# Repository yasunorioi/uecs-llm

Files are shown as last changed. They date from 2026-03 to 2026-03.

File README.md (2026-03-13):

# AgriHA (uecs-llm)

LLM による温室環境制御システム — 三層自律制御アーキテクチャ

## アーキテクチャ

```
┌─────────────────────────────────────────────────────────┐
│ Raspberry Pi (AgriHA) — 全制御をオンボード実行           │
│                                                         │
│  ┌── Layer 1: 緊急制御 ──────────────────────────────┐  │
│  │ emergency_guard.sh (cron 1分)                     │  │
│  │ 高温/低温→即時開窓・ロックアウト                   │  │
│  └──────────────────────────────────────────────────┘  │
│  ┌── Layer 2: ルールベース制御 ──────────────────────┐  │
│  │ rule_engine.py (cron 5分)                         │  │
│  │ YAML定義ルール→灌水・換気・強風・降雨制御         │  │
│  │ ピタゴラスイッチ: 5段階側窓開度制御+位置追跡       │  │
│  └──────────────────────────────────────────────────┘  │
│  ┌── Layer 3: LLM予報制御 ──────────────────────────┐  │
│  │ forecast_engine.py (cron 1時間)                   │  │
│  │ NullClaw(デフォルト) or クラウドLLM API            │  │
│  │ → 天気予報+1時間制御計画生成                       │  │
│  │ plan_executor.py (cron 10分) → 計画実行            │  │
│  └──────────────────────────────────────────────────┘  │
│                                                         │
│  NullClaw Proxy (port 3001): オフラインLLM推論          │
│  unipi-daemon: センサー・リレー・MQTT・REST API         │
│  agriha-ui: ローカルWebUI (FastAPI+htmx, ポート8501)   │
│  LINE Bot: RPi上で直接稼働 (agriha-ui内)               │
├─────────────────────────────────────────────────────────┤
│ UniPi 1.1 ハードウェア                                  │
│  MCP23008 リレー(8ch) + DS18B20 + GPIO DI + Misol RS485│
│                                                         │
│ USB SIMモデム (オプション): 固定回線不要な圃場向け       │
└─────────────────────────────────────────────────────────┘
```

## 設計原則

- **下層が上層を黙らせる**: Layer 1ロックアウト中はLayer 2/3は動作しない
- **各層独立動作**: 上層が死んでも下層の安全機構は生きる
- **RPi単一構成**: 全てRaspberry Pi上で完結（VPS不要）
- **オフラインファースト**: デフォルトはNullClaw（ローカルLLM）、API不要・無料
- **マルチLLM対応**: OpenAI SDK互換でClaude/GPT/Gemini/NullClaw/Ollamaを切替可能

## NullClaw（デフォルトLLMプロバイダー）

NullClawをデフォルトLLMとして採用。APIキー不要・オフライン動作・無料。

- **nullclaw_proxy.py** (port 3001): OpenAI API互換プロキシ。NullClaw CLIをラップし `/v1/chat/completions` エンドポイントを提供
- **NullClawFallbackClient**: forecast_engine.py内のクライアント。APIキーあり→クラウドAPI優先→失敗時NullClawフォールバック。APIキーなし→NullClaw直行
- **制約**: NullClawはtool calling非対応。センサーデータはプロンプト埋め込みで代替

```
APIキーなし (デフォルト)     APIキーあり
      │                          │
      ▼                          ▼
  NullClaw直行           クラウドAPI試行
  (localhost:3001)              │
                          成功? ─┬─ Yes → クラウド応答
                                └─ No  → NullClawフォールバック
```

## LINE Bot

RPi上のagriha-ui内で直接稼働（VPS不要）。Cloudflare TunnelまたはNginx+Let's Encryptで外部公開。

- LLMプロバイダーにはNullClawFallbackClientを使用（設定画面の選択に従う）
- NullClaw使用時はtool calling不可のため、リレー制御（set_relay）は利用不可
- クラウドLLM使用時はget_sensors / get_status / set_relay のtool callingが利用可能

## ディレクトリ構成

| パッケージ | 場所 | 説明 |
|---|---|---|
| `agriha.control` | `src/agriha/control/` | 三層制御（emergency_guard, rule_engine+ピタゴラスイッチ, forecast_engine, plan_executor, window_position） |
| `agriha.control` | `src/agriha/control/nullclaw_proxy.py` | NullClaw OpenAI互換プロキシ (port 3001) |
| `agriha.daemon` | `src/agriha/daemon/` | ハードウェアデーモン（I2C, GPIO, MQTT, REST API, rain_detector, uart_co2_reader） |
| `agriha.chat` | `src/agriha/chat/` | ローカルWebUI（ダッシュボード+設定画面+サービス再起動+LINE Bot） |
| `agriha.vps` | `src/agriha/vps/` | LINE Bot VPS版（systemd + venv） |
| `firmware` | `firmware/arduino/`, `firmware/pico/` | マイコンファームウェア（Arduino W5500 PoE, Pico CircuitPython） |
| `hardware` | `hardware/kicad/` | KiCad基板設計（Grove Shield, Actuator） |
| `config` | `config/` | 設定テンプレート（rules.yaml, channel_map.yaml, forecast.yaml等） |

## セットアップ

```bash
# 1. clone
sudo git clone https://github.com/yasunorioi/uecs-llm.git /opt/agriha
cd /opt/agriha

# 2. セットアップ（ユーザー作成+venv+systemd+NullClaw全部入り）
sudo bash setup.sh

# 3. (オプション) クラウドLLMを使う場合のみAPIキー設定
sudo nano /opt/agriha/.env

# 4. 起動
sudo systemctl start unipi-daemon agriha-ui agriha-nullclaw-proxy
```

`sudo bash setup.sh` で以下が完了する:
- Python venv作成 + パッケージインストール
- NullClaw CLIインストール + agriha-nullclaw-proxy.service 有効化
- `/etc/agriha/` に設定ファイル配置
- `/var/lib/agriha/`, `/var/log/agriha/` ディレクトリ作成
- agriha システムユーザー作成 + 所有権設定
- systemd サービス有効化（unipi-daemon, agriha-ui, agriha-nullclaw-proxy）
- 三層制御 cron 設定
- Nginx + Let's Encrypt HTTPS設定（LINE Bot外部公開用）
- USB SIMモデム検出時: ModemManager + NetworkManager APN自動設定

## systemd サービス一覧

| サービス | 説明 |
|---|---|
| `unipi-daemon.service` | センサー・リレー・MQTT・REST APIデーモン |
| `agriha-ui.service` | Web UI + LINE Bot (FastAPI, ポート8501) |
| `agriha-nullclaw-proxy.service` | NullClaw OpenAI互換プロキシ (ポート3001) |
| `rain_detector.service` | 雨検知デーモン |
| `uart_co2_reader.service` | UART CO2センサー読み取りデーモン |
| `ModemManager.service` | USB SIMモデム管理（SIM使用時） |
| `certbot.timer` | Let's Encrypt証明書自動更新 |

## Web UI 設定画面

`http://<RPi-IP>:8501/settings` から以下を編集可能:

- **LLMプロバイダー**: プルダウンで NullClaw / Anthropic(Claude) / OpenAI / Gemini / Ollama 選択
- **APIキー設定**: NullClaw以外を選択した場合のみ必要
- **システムプロンプト**: Layer 3 LLMへの指示文
- **緊急閾値**: Layer 1 の高温/低温閾値
- **制御ルール**: Layer 2 の rules.yaml（YAML直接編集+構文チェック）
- **チャンネルマップ**: リレーチャンネル割当（channel_map.yaml）
- **LLM詳細設定**: forecast.yaml 直接編集（上級者向け）

## LLMプロバイダー切替

forecast_engine.py は OpenAI SDK 互換クライアント（NullClawFallbackClient）を使用。
設定画面のプルダウンから選択するか、forecast.yaml を直接編集。

| プロバイダー | base_url | APIキー | 備考 |
|---|---|---|---|
| NullClaw (デフォルト) | `http://localhost:3001/v1/` | 不要 | オフライン・無料・tool calling不可 |
| Anthropic (Claude) | `https://api.anthropic.com/v1/` | 必要 | 高精度・tool calling可 |
| OpenAI (GPT) | `https://api.openai.com/v1/` | 必要 | tool calling可 |
| Google (Gemini) | `https://generativelanguage.googleapis.com/v1beta/openai/` | 必要 | tool calling可 |
| Ollama (ローカル) | `http://localhost:11434/v1/` | 不要 | 要Ollama別途インストール |

## USB SIM / APN設定

固定回線のない圃場向けに、USB SIMモデムによるモバイル回線接続をサポート。

- setup.sh実行時にUSBモデムを自動検出し、ModemManager + NetworkManagerを設定
- APN設定はプリセットから選択: **SORACOM** (デフォルト) / IIJmio / 手動入力
- ArSprout既存USB SIM環境との互換性あり（既存設定を検出した場合は上書きしない）

## VPS LINE Bot デプロイ

VPSをLINE Bot + 農家WireGuard VPNサーバとして構築する手順。
VPSはメッセージルーターとして動作し、LLM処理は各農家のRPiで行う。

### 1. 設定ファイル編集

```bash
# VPSでリポジトリをclone
git clone https://github.com/yourname/uecs-llm.git /opt/uecs-llm
cd /opt/uecs-llm

# 環境設定を編集（ドメイン、ポート、パス等）
vi config/vps.conf
```

`config/vps.conf` の編集項目:

| 変数 | 説明 | デフォルト |
|---|---|---|
| `DOMAIN` | ドメイン名（SSL証明書・QR URL） | `toiso.fit` |
| `APP_PORT` | uvicornリッスンポート | `8443` |
| `DEPLOY_DIR` | デプロイ先シンボリックリンク | `/opt/agriha-linebot` |
| `QR_DIR` | QR画像配信ディレクトリ | `/var/www/qr` |
| `WG_INTERFACE` | WireGuardインターフェース名 | `wg-farmers` |
| `WG_PORT` | WireGuard UDPポート | `51821` |
| `WG_SERVER_IP` | WireGuardサーバIP/CIDR | `10.20.0.1/24` |

### 2. セットアップ実行

```bash
# WireGuard 農家VPNサーバ構築
sudo bash scripts/wg_farmers_vps_setup.sh

# LINE Bot + nginx + systemd セットアップ
sudo bash scripts/deploy_vps_linebot.sh --setup

# .env作成（LINE トークン、WG公開鍵等）
# NOTE: KEY=VALUE形式のみ。"export" は付けない（systemd EnvironmentFile非対応）
sudo cp /opt/agriha-linebot/.env.example /opt/agriha-linebot/.env
sudo vi /opt/agriha-linebot/.env
sudo chown www-data:www-data /opt/agriha-linebot/.env

# サービス起動
sudo systemctl start agriha-linebot
curl https://your-domain/health
```

### 3. コード更新

```bash
cd /opt/uecs-llm
sudo bash scripts/deploy_vps_linebot.sh
# → git pull + pip差分 + サービス再起動
```

### テンプレートファイル

| テンプレート | 展開先 | 説明 |
|---|---|---|
| `config/nginx-vps.conf.template` | `/etc/nginx/sites-available/${DOMAIN}` | nginx設定 |
| `systemd/agriha-linebot.service.template` | `/etc/systemd/system/agriha-linebot.service` | systemdサービス |

テンプレート内の `__DOMAIN__`, `__APP_PORT__` 等のプレースホルダは `deploy_vps_linebot.sh --setup` が `config/vps.conf` の値で自動置換する。

## テスト

```bash
pip install -e ".[dev]"
pytest tests/ -v
```

## ライセンス

MIT

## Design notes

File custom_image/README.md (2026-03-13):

# UniPi Agri HA カスタムイメージ

Arsproutからの完全移行用カスタムRaspbian イメージ

## 構成

```
Raspbian Lite 64-bit (bookworm)
├── Docker + Docker Compose
│   ├── Home Assistant（制御・ローカルUI）
│   ├── Node-RED（農業ロジック）
│   └── Mosquitto（MQTTブローカー）
├── EVOK（UniPi 1.1制御）
├── WireGuard（VPN）
├── RS485気象センサーサービス
├── 設定バックアップcron
└── カメラ対応（オプション）
```

## データ保存方針

- **ローカル（Pi）**: 制御・一時データのみ
- **クラウド（さくら）**: 長期保存（InfluxDB, Grafana, カメラ画像）
- **設定バックアップ**: 毎日クラウドへ同期

## ファイル構成

```
custom_image/
├── scripts/
│   ├── build_image.sh      # イメージビルドスクリプト
│   ├── first_boot.sh       # 初回起動時セットアップ
│   ├── install_evok.sh     # EVOK インストール
│   ├── install_docker.sh   # Docker インストール
│   └── backup_config.sh    # 設定バックアップ
├── config/
│   ├── wg0.conf.template   # WireGuard設定テンプレート
│   ├── evok.conf           # EVOK設定
│   └── settings.yaml       # デバイス固有設定
├── docker/
│   ├── docker-compose.yaml # HA + Node-RED + Mosquitto
│   └── ha-config/          # Home Assistant設定
└── overlays/
    └── config.txt          # /boot/config.txt 追記内容
```

## ビルド手順

1. Raspbian Lite 64-bit イメージをダウンロード
2. `build_image.sh` でイメージをカスタマイズ
3. SDカードに書き込み
4. 初回起動時に `first_boot.sh` が実行される

## 対応ハードウェア

- Raspberry Pi 3B/3B+/4B/Zero 2 W
- UniPi 1.1（I2C接続）
- RS485 USB-Serialアダプタ（CH341等）
- PoE IPカメラ（オプション）

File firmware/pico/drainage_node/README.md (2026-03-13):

# Drainage Sensor Node - MQTT Version

CircuitPython firmware for greenhouse drainage monitoring using DFRobot SEN0575 tipping bucket sensor with MQTT communication.

---

## Hardware Requirements

### Components
- **W5500-EVB-Pico-PoE** - Raspberry Pi Pico compatible board with Ethernet and PoE support
- **DFRobot SEN0575** - Gravity Tipping Bucket Rainfall Sensor
- **Ethernet Cable** - Cat5e or better
- **PoE Injector** - Optional, for power over Ethernet

### Wiring

#### W5500 SPI (Pre-wired on W5500-EVB-Pico-PoE)
- GP16: MISO
- GP17: CS
- GP18: SCK
- GP19: MOSI

#### DFRobot SEN0575 I2C Connection
| Sensor Pin | Pico Pin | Description |
|---|---|---|
| VCC | 3.3V | Power supply |
| GND | GND | Ground |
| SDA | GP4 | I2C Data |
| SCL | GP5 | I2C Clock |

---

## Software Requirements

### CircuitPython
- **Version**: 9.0.0 or later
- **Download**: https://circuitpython.org/board/wiznet_w5500_evb_pico/

### Required Libraries
Install these libraries to the `/lib` folder on CIRCUITPY drive:

1. **adafruit_wiznet5k** - W5500 Ethernet driver
2. **adafruit_minimqtt** - MQTT client
3. **adafruit_bus_device** - I2C device helper

Download from: https://circuitpython.org/libraries

---

## Installation

### Step 1: Flash CircuitPython
1. Download CircuitPython UF2 file for W5500-EVB-Pico
2. Hold BOOTSEL button while connecting USB
3. Drag and drop UF2 file to RPI-RP2 drive
4. Board will restart with CIRCUITPY drive

### Step 2: Install Libraries
1. Download Adafruit CircuitPython Library Bundle
2. Copy required libraries from bundle to `/lib` on CIRCUITPY:
   ```
   /lib/adafruit_wiznet5k/
   /lib/adafruit_minimqtt/
   /lib/adafruit_bus_device/
   /lib/dfrobot_rainfall.py  (included in this project)
   ```

### Step 3: Deploy Firmware
1. Copy `code.py` to root of CIRCUITPY drive
2. Copy `settings.toml` to root of CIRCUITPY drive
3. Edit `settings.toml` with your network and MQTT settings
4. Board will auto-restart and run firmware

---

## Configuration

Edit `settings.toml` before deployment:

```toml
# House identification
HOUSE_ID = "h1"

# Network (Static IP)
STATIC_IP = "192.168.1.70"
SUBNET = "255.255.255.0"
GATEWAY = "192.168.1.1"
DNS = "8.8.8.8"

# MQTT Broker
MQTT_BROKER = "192.168.1.10"
MQTT_PORT = "1883"
MQTT_USER = ""  # Optional
MQTT_PASS = ""  # Optional

# Sensor I2C Address
SENSOR_I2C_ADDR = "0x1D"

# Publish interval (seconds)
PUBLISH_INTERVAL = "600"  # 10 minutes
```

---

## MQTT Topics

### Published Topics
- `greenhouse/{HOUSE_ID}/drainage/amount` - Drainage amount (JSON)
- `greenhouse/{HOUSE_ID}/drainage/rate` - Drainage rate (JSON)
- `greenhouse/{HOUSE_ID}/drainage/count` - Tip count (JSON)
- `greenhouse/{HOUSE_ID}/drainage/status` - Online/Offline status

### Subscribed Topics
- `greenhouse/{HOUSE_ID}/drainage/reset` - Reset command (payload: "reset" or "1")

### Payload Format

**Amount:**
```json
{
  "timestamp": "2026-02-05T10:30:00",
  "amount_mm": 2.5,
  "total_mm": 15.8,
  "interval_sec": 600
}
```

**Rate:**
```json
{
  "timestamp": "2026-02-05T10:30:00",
  "rate_mm_min": 0.25
}
```

**Count:**
```json
{
  "timestamp": "2026-02-05T10:30:00",
  "count": 45
}
```

---

## Home Assistant Integration

### MQTT Discovery

Firmware automatically publishes Home Assistant MQTT Discovery configuration on startup. Sensors will appear as:

- `sensor.{house_id}_drainage_amount` - Drainage amount (mm)
- `sensor.{house_id}_drainage_rate` - Drainage rate (mm/min)

### Manual Configuration

If auto-discovery is disabled, add to `configuration.yaml`:

```yaml
mqtt:
  sensor:
    - name: "H1 Drainage Amount"
      state_topic: "greenhouse/h1/drainage/amount"
      unit_of_measurement: "mm"
      device_class: precipitation
      value_template: "{{ value_json.amount_mm }}"

    - name: "H1 Drainage Rate"
      state_topic: "greenhouse/h1/drainage/rate"
      unit_of_measurement: "mm/min"
      value_template: "{{ value_json.rate_mm_min }}"
```

---

## Operation

### Normal Operation
1. Board connects to Ethernet on startup
2. Connects to MQTT broker
3. Publishes sensor readings every 10 minutes (configurable)
4. Performs daily reset at midnight (00:00)

### Status Monitoring

**Serial Console (USB):**
```bash
# Linux/Mac
screen /dev/ttyACM0 115200

# Windows
# Use PuTTY or Tera Term
```

**Expected Output:**
```
==================================================
Drainage Sensor Node - MQTT Version
==================================================
Initializing W5500 Ethernet...
IP Address: 192.168.1.70
Initializing I2C...
Initializing DFRobot Rainfall Sensor (I2C: 0x1D)...
Sensor initialized successfully!
Setting up MQTT client (Broker: 192.168.1.10:1883)...
Connected to MQTT broker! (RC: 0)
Publishing Home Assistant MQTT Discovery...
==================================================
Starting main loop...
Publish interval: 600 seconds
==================================================
```

### LED Indicators
- **Power LED**: Solid = Board powered
- **W5500 Link LED**: Solid = Ethernet connected
- **W5500 Activity LED**: Blinking = Network traffic

---

## Troubleshooting

### Sensor Not Detected
**Symptom:** `ERROR: Sensor initialization failed!`

**Solutions:**
1. Check I2C wiring (SDA, SCL, VCC, GND)
2. Verify sensor power (3.3V)
3. Test I2C address:
   ```python
   # Add to code.py temporarily
   import board
   import busio
   i2c = busio.I2C(board.GP5, board.GP4)
   while not i2c.try_lock():
       pass
   devices = i2c.scan()
   print("I2C devices found:", [hex(d) for d in devices])
   i2c.unlock()
   ```
4. Expected address: `0x1d`

### MQTT Connection Failed
**Symptom:** `MQTT connection failed: [Errno 113] EHOSTUNREACH`

**Solutions:**
1. Verify MQTT broker IP in `settings.toml`
2. Check broker is running: `mosquitto_sub -h 192.168.1.10 -t '#' -v`
3. Check network connectivity: Ping broker from another device
4. Verify firewall allows port 1883

### No Data Published
**Symptom:** MQTT connected but no sensor data

**Solutions:**
1. Check serial console for errors
2. Verify sensor is receiving rainfall events
3. Check publish interval (default: 10 minutes)
4. Monitor MQTT topic: `mosquitto_sub -h 192.168.1.10 -t 'greenhouse/+/drainage/#' -v`

### Ethernet Not Connecting
**Symptom:** `Ethernet connection timeout`

**Solutions:**
1. Check Ethernet cable connection
2. Verify static IP settings in `settings.toml`
3. Check router/switch port is active
4. Try DHCP temporarily (modify code.py: `is_dhcp=True`)

---

## Maintenance

### Sensor Calibration
Default: 0.2794 mm per tip (factory calibration)

To recalibrate:
1. Collect known volume of water (e.g., 100ml)
2. Pour into sensor funnel
3. Count number of tips
4. Calculate: `mm_per_tip = (volume_ml / funnel_area_cm2) / tip_count * 10`
5. Update in sensor driver (requires code modification)

### Daily Reset
Sensor cumulative values reset automatically at midnight (00:00).

Manual reset:
```bash
mosquitto_pub -h 192.168.1.10 -t 'greenhouse/h1/drainage/reset' -m 'reset'
```

---

## File Structure

```
drainage_node/
├── code.py              # Main firmware
├── settings.toml        # Configuration
└── README.md            # This file

/lib/
└── dfrobot_rainfall.py  # Sensor driver
```

---

## References

- **DFRobot SEN0575 Datasheet**: https://wiki.dfrobot.com/SKU_SEN0575
- **CircuitPython Documentation**: https://docs.circuitpython.org/
- **W5500-EVB-Pico Schematic**: https://docs.wiznet.io/Product/iEthernet/W5500/w5500-evb-pico
- **MQTT Protocol**: https://mqtt.org/

---

## License

This firmware is part of the Arsprout greenhouse automation project.

**Author**: Arsprout Analysis Team
**Date**: 2026-02-05
**Version**: 1.0.0

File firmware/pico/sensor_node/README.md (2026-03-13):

# センサーノード ファームウェア

W5500-EVB-Pico2 + Grove Shield を使用したセンサーノード

## 動作確認済み (2026-02-05)

- E2E通信成功: センサー → MQTT → Mosquitto

## ハードウェア構成

| コンポーネント | 型番 | I2Cアドレス |
|---|---|---|
| メインボード | W5500-EVB-Pico2 | - |
| 温湿度センサー | SHT40 | 0x44 |
| 気圧センサー | BMP280 | 0x76 |
| CO2センサー | SCD41 | 0x62 |

## ピン配置

### I2C (Grove Shield)
- SDA: GP8
- SCL: GP9

### W5500 SPI
- SCK: GP18
- MOSI: GP19
- MISO: GP16
- CS: GP17
- RST: GP20

## 必要ライブラリ

```bash
circup install adafruit_sht4x adafruit_bmp280 adafruit_scd4x adafruit_minimqtt adafruit_requests
```

## MQTT トピック

- `greenhouse/sensors` - センサーデータ (JSON)

### ペイロード例

```json
{"temp": 25.3, "hum": 56.4, "press": 1004.3}
```

## 使い方

1. `code.py` を CIRCUITPY ドライブにコピー
2. `settings.toml` でMQTTブローカーのIPを設定
3. 電源投入で自動起動

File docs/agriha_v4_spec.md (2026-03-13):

# AgriHA v4 仕様書

> **Version**: 4.0-draft
> **Generated**: 2026-03-04
> **Source**: v3-rebuild branch + cmd_304 research + Memory MCP
> **正データ: v3-rebuildブランチの実コードのみ。v3.x設計書は参考程度。**

---

## §1 機能一覧

### 1.1 機能カタログ

| # | カテゴリ | 機能 | ステータス | 優先度 | 実装場所 |
|---|---|---|---|---|---|
| F01 | リモート制御 | LINE Bot「開けろ/閉めろ」 | RPi移植設計済み | P0 | src/agriha/chat/app.py + linebot_handler.py |
| F02 | 状況確認 | LINE Bot「今どうなってる？」 | RPi移植設計済み | P0 | src/agriha/chat/app.py + linebot_handler.py |
| F03 | 異常通知 | emergency_guard.sh LINE通知 | 実装済み | P1 | src/agriha/control/emergency_guard.sh |
| F04 | 自動制御 | Layer1: 緊急停止 | 実装済み | P1 | src/agriha/control/emergency_guard.sh |
| F05 | 自動制御 | Layer2: ルールベース+ピタゴラスイッチ | 実装済み | P2 | src/agriha/control/rule_engine.py + window_position.py |
| F06 | 自動制御 | Layer3: LLM 1時間予報 | 実装済み | P2 | src/agriha/control/forecast_engine.py |
| F07 | 自動制御 | 計画実行（plan_executor） | 実装済み | P2 | src/agriha/control/plan_executor.py |
| F08 | 自動制御 | 日射比例灌水 | 実装済み | P2 | src/agriha/control/rule_engine.py |
| F09 | UI | ダッシュボード+設定画面+サービス再起動 | 実装済み | P2 | src/agriha/chat/ (templates/static) |
| F10 | UI | Chat窓（Claude対話） | 実装済み | P2 | src/agriha/chat/app.py |
| F11 | HW抽象化 | unipi-daemon（センサー+リレー） | 実装済み | P1 | src/agriha/daemon/ |
| F12 | HW抽象化 | 雨検知（rain_detector） | 実装済み | P2 | src/agriha/daemon/rain_detector.py |
| F13 | HW抽象化 | CO2読取（uart_co2_reader） | 実装済み | P3 | src/agriha/daemon/uart_co2_reader.py |
| F14 | インフラ | カメラ定点撮影 | 実装済み | P3 | scripts/agriha-capture.sh |
| F15 | インフラ | Nginx統合 | 設計済み(config/nginx.conf) | P3 | config/nginx.conf |
| F16 | 蒸留 | 判断パターン蒸留パイプライン | 部分実装 | P4 | src/agriha/control/distiller.py |
| F17 | UI | 反省会モード（週次LINE Bot） | 設計済み(config有) | P4 | config/reflection.yaml |
| F18 | 設定 | channel_map.yaml外部設定 | 実装済み | P1 | config/channel_map.yaml + channel_config.py |
| F19 | ネットワーク | USB SIM / APN設定UI | 設計済み | P1 | src/agriha/chat/app.py (settings画面) + ModemManager |
| F20 | ネットワーク | HTTPS証明書管理 | 設計済み | P1 | certbot + Nginx |
| F21 | 自動制御 | ピタゴラスイッチ段階制御 | **実装済み** | P2 | src/agriha/control/rule_engine.py + window_position.py |

### 1.2 優先度定義

| 優先度 | 意味 | 基準 |
|---|---|---|
| P0 | 最重要 | 農家が毎日使う。停止＝業務不能 |
| P1 | 必須 | 安全装置。停止＝作物リスク |
| P2 | 重要 | 自動制御の中核。手動で代替可 |
| P3 | 便利 | あると便利。なくても運用可 |
| P4 | 将来 | 構想段階。1年分データ蓄積後に着手 |

### 1.3 設計思想（Memory MCP: tono-preferences）

- **マクガイバー精神**: シンプル・ローコスト・手元の道具で解決
- **三層構造**: 爆発（緊急停止）→ガムテ（ルールベース）→知恵（LLM）。下ほど確実、どの層が欠けても下が支える
- **怒り駆動開発**: LINEへのクレーム→system_prompt.txtに追記→制御ロジックになる
- **LLM自然減衰**: 初期はLLM毎時→パターン蓄積→ルールに蒸留→API代が自然減衰
- **機能優先順位**: 1位「開けろ/閉めろ」> 2位「今どうなってる？」> 3位 異常値通知 > 4位 自動制御

---

## §2 アーキテクチャ

### 2.1 システム構成図（2ノード + VPSオプション）

```
LINE Platform                    VPS (オプション)
  │ Webhook POST                 ┌──────────────────────────┐
  │ (HTTPS/443)                  │ Grafana + InfluxDB       │
  │                              │ + Telegraf               │
  │                              │ :3000 (監視用、必須ではない) │
  │                              └──────────────────────────┘
  │
  │  Let's Encrypt + 固定IP (USB SIM)
  │
┌─┴─────────────────────────────────────────────────────────┐
│                RPi (Raspberry Pi 4B)                        │
│                                                             │
│  ┌─────────────┐  ┌─────────────┐  ┌─────────────┐       │
│  │ unipi-daemon│  │ agriha-ui   │  │ Mosquitto   │       │
│  │ (systemd)   │  │ (systemd)   │  │ MQTT Broker │       │
│  │ :8080       │  │ :8501       │  │ :1883       │       │
│  │ REST API    │  │ FastAPI     │  │             │       │
│  │ +MQTT pub   │  │ Chat+Dash   │  │             │       │
│  │             │  │ +LINE Bot   │  │             │       │
│  │             │  │ +Settings   │  │             │       │
│  └──────┬──────┘  └──────┬──────┘  └──────┬──────┘       │
│         │                │                │               │
│         │   ┌────────────┴────────┐       │               │
│         │   │ cron scripts        │       │               │
│         │   │ emergency_guard.sh  │◄──────┘               │
│         │   │ rule_engine.py      │  MQTT                 │
│         │   │ forecast_engine.py  │  subscribe            │
│         │   │ plan_executor.py    │                        │
│         │   └─────────────────────┘                        │
│         │                                                  │
│  ┌──────┴──────┐  ┌──────────────┐  ┌──────────────┐     │
│  │ NullClaw    │  │ Nginx        │  │ USB SIM      │     │
│  │ Proxy       │  │ (HTTPS/443)  │  │ ドングル     │     │
│  │ :3001       │  │ + HTTP/80    │  │ (セルラー)   │     │
│  └─────────────┘  └──────────────┘  └──────────────┘     │
│                                                             │
│  ┌──────────────────────────────────────────────────┐     │
│  │ Hardware Layer                                     │     │
│  │ I2C: MCP23008 → 8ch Relay (ch1-8)                │     │
│  │ 1-Wire: DS18B20 → 内温                            │     │
│  │ UART RS485: Misol WH65LP → 気象(温湿度/風/雨)     │     │
│  │ UART: CDM7160/K30/SCD30 → CO2                    │     │
│  │ GPIO: DI07-14 → 緊急スイッチ                       │     │
│  └──────────────────────────────────────────────────┘     │
│                                                             │
│  ┌──────────────────┐  ┌──────────────────┐               │
│  │ rain_detector    │  │ uart_co2_reader  │               │
│  │ (systemd)        │  │ (systemd)        │               │
│  └──────────────────┘  └──────────────────┘               │
└─────────────────────────────────────────────────────────────┘
           │
    ┌──────┴──────┐
    │  ハウス内    │
    ├─────────────┤
    │ Pico W      │ Arduino, W5500 Ethernet
    │ env_node    │ → MQTT → unipi-daemon
    │ solar_node  │
    └─────────────┘
```

### 2.2 ディレクトリ構成

> **2026-03-13更新**: unipi-agri-ha / uecs-pico-gateway から全アクティブコードを統合し、uecs-llm をモノレポ化。

```
uecs-llm/
├── config/                    # 全設定ファイル統一
│   ├── channel_map.yaml       # リレーch↔機器マッピング
│   ├── crop_irrigation.yaml   # 灌水パラメータ
│   ├── emergency.conf         # 緊急閾値
│   ├── forecast.yaml          # LLMプロバイダー・パラメータ
│   ├── network.yaml           # ネットワーク設定
│   ├── nginx.conf             # Nginx設定テンプレート
│   ├── reflection.yaml        # 反省会モード設定
│   ├── rule_candidates.yaml   # LLM生成ルール候補
│   ├── rules.yaml             # ルールエンジン設定（PID/灌水/風/温度/ピタゴラスイッチ）
│   ├── system_prompt.txt      # LLMシステムプロンプト
│   ├── thresholds.yaml        # アラーム閾値
│   ├── unipi_daemon.example.yaml # unipi-daemon設定テンプレート
│   └── wg0.conf.template      # WireGuard設定テンプレート
├── src/agriha/                # 全Pythonソース統一パッケージ
│   ├── control/               # 三層制御 + executor
│   │   ├── emergency_guard.sh # Layer 1: 緊急制御（bash）
│   │   ├── rule_engine.py     # Layer 2: ルールベース+ピタゴラスイッチ
│   │   ├── forecast_engine.py # Layer 3: LLM予報
│   │   ├── plan_executor.py   # Layer 3: 計画実行
│   │   ├── window_position.py # 側窓推定位置管理
│   │   ├── nullclaw_proxy.py  # NullClaw OpenAI互換プロキシ
│   │   ├── channel_config.py  # チャンネルマップ読み込み
│   │   ├── rule_manager.py    # ルールYAMLパーサ
│   │   ├── distiller.py       # 蒸留パイプライン
│   │   └── retry_helper.py    # リトライロジック
│   ├── chat/                  # WebUI + LINE Bot（RPi直接稼働）
│   │   ├── app.py             # FastAPI + htmx + 設定画面 + サービス再起動
│   │   ├── linebot_handler.py # LINE Webhook統合
│   │   ├── templates/         # Jinja2テンプレート
│   │   └── static/            # CSS/JS
│   ├── daemon/                # HW抽象化デーモン + 補助サービス
│   │   ├── main.py            # 5タスク並行asyncioデーモン
│   │   ├── rest_api.py, sensor_loop.py
│   │   ├── i2c_relay.py, gpio_watch.py, ds18b20.py
│   │   ├── wh65lp_reader.py, mqtt_relay_bridge.py
│   │   ├── ccm_receiver.py, emergency_override.py
│   │   ├── rain_detector.py   # 雨検知デーモン
│   │   └── uart_co2_reader.py # UART CO2リーダー
│   ├── vps/                   # LINE Bot VPS版（Docker、レガシー）
│   │   ├── app.py, llm_client.py, router.py, tools.py
│   │   ├── rpi_client.py, onboarding.py
│   │   └── tests/
│   └── linebot/               # LINE Bot共通モジュール
├── tests/                     # 全テスト統一（pytest tests/）
│   ├── control/               # 三層制御テスト（ピタゴラスイッチ含む）
│   ├── daemon/                # デーモンテスト
│   ├── chat/                  # UIテスト
│   └── linebot/               # LINE Botテスト
├── firmware/                  # マイコンファームウェア
│   ├── arduino/               # Arduino (W5500 Ethernet PoE)
│   │   ├── env_node_eth/      # 環境センサーノード (SCD41+SHT40+BMP280)
│   │   ├── solar_node/        # 日射センサーノード
│   │   └── shared/            # 共通ヘッダ
│   └── pico/                  # CircuitPython (Pico 2 W)
│       ├── sensor_node/       # W5500-EVB-Pico2センサー
│       ├── drainage_node/     # 排水制御
│       └── weather_node/      # 気象ステーション
├── hardware/kicad/            # KiCad基板設計（Grove Shield, Actuator）
├── systemd/                   # systemdサービスファイル統一
├── scripts/                   # デプロイ・WG・ユーティリティ
├── custom_image/              # RPi OSカスタムイメージビルド (pi-gen)
├── auto_test/                 # 自動テストフレームワーク (udev+systemd)
├── benchmarks/                # LLM制御ベンチマーク
├── docker/                    # RPi用 (Mosquitto)
├── cloud_server/              # VPS用 (InfluxDB+Telegraf+Grafana、オプション)
├── docs/                      # 設計書
└── pyproject.toml             # プロジェクト定義
```

### 2.3 データフロー図

```
                    ┌──────────────┐
                    │ Visual       │
                    │ Crossing API │
                    └──────┬───────┘
                           │ HTTPS (毎時, TTL 1h cache)
                           ▼
┌───────────────┐   ┌──────────────┐   ┌──────────────┐
│ Misol WH65LP  │   │ forecast     │   │ Claude       │
│ (気象センサー) │   │ _engine.py   │──▶│ Haiku API    │
└───────┬───────┘   │ (cron 毎時)  │   └──────────────┘
        │UART       └──────┬───────┘
        ▼                  │ current_plan.json
┌───────────────┐   ┌──────▼───────┐   ┌──────────────┐
│ unipi-daemon  │◄──│ plan         │   │ 高札API      │
│ :8080         │   │ _executor.py │   │ (類似検索)   │
│ REST API      │   │ (cron 5分)   │   └──────────────┘
│ +MQTT publish │   └──────────────┘
└───────┬───────┘          ▲
        │                  │ flag files
┌───────▼───────┐   ┌──────┴───────┐
│ MCP23008      │   │ rule         │
│ 8ch Relay     │   │ _engine.py   │
│ (I2C)         │   │ (cron 10分)  │
└───────────────┘   └──────┬───────┘
                           ▲
┌───────────────┐   ┌──────┴───────┐
│ DS18B20       │   │ emergency    │
│ (内温)        │   │ _guard.sh    │
└───────────────┘   │ (cron 毎分)  │
                    └──────────────┘

センサー → MQTT → unipi-daemon キャッシュ → REST API → 制御スクリプト群
制御スクリプト → POST /api/relay/{ch} → MQTT publish → MCP23008 Relay → 物理動作
```

### 2.4 通信プロトコル

| 経路 | プロトコル | 詳細 |
|---|---|---|
| センサー→RPi | MQTT (mosquitto :1883) | Pico W → MQTT publish → unipi-daemon subscribe |
| RPi内部 | REST API (localhost) | unipi-daemon :8080 ← 制御スクリプト群 |
| RPi内部 | MQTT | unipi-daemon → relay/{ch}/set → MCP23008 |
| RPi→Claude | HTTPS | forecast_engine.py → Claude Haiku API (オプション) |
| RPi→天気 | HTTPS | forecast_engine.py → Visual Crossing API |
| RPi→LINE | HTTPS | emergency_guard.sh → LINE Notify API, linebot_handler → LINE Reply/Push API |
| LINE→RPi | HTTPS | LINE Platform → Webhook POST → RPi (Let's Encrypt + 固定IP) |
| RPi内部 | HTTP | agriha-ui → NullClaw Proxy (localhost:3001) |

### 2.5 MQTTトピック体系

```
agriha/
  {house_id}/                     # 例: h01
    sensor/
      DS18B20                     # 内温 (retain=True)
    relay/
      {ch}/set                    # リレー制御コマンド
      state                       # リレー状態一括 (retain=True)
    ccm/
      #                           # UECS-CCM変換データ
  farm/
    weather/
      misol                       # 気象データ (retain=True)
```

---

## §3 各機能の仕様

### §3.1 emergency_guard.sh（Layer1: 緊急停止）

**概要**: 最下層の安全装置。bash + curl のみで動作し、Python不要。毎分cronで実行。

| 項目 | 内容 |
|---|---|
| **入力** | GET localhost:8080/api/sensors → `indoor_temp` |
| **設定** | /etc/agriha/emergency.conf (temp_high=40, temp_low=5) |
| **処理** | 温度閾値チェック → 全窓操作 + lockout + LINE通知 |
| **出力** | POST /api/relay/{ch} (全窓ch), /var/lib/agriha/lockout 作成, LINE Notify |
| **依存** | unipi-daemon REST API, LINE Notify API |
| **コード行数** | 240行 |

**閾値と動作**:

| 条件 | 動作 | LINE通知 |
|---|---|---|
| 内温 ≥ 40℃ | 全窓全開(value=1) + lockout発動 | 🚨高温緊急: {temp}℃ 全窓全開 |
| 内温 ≤ 5℃ | 全窓全閉(value=0) + lockout発動 | 🚨低温緊急: {temp}℃ 全窓全閉 |
| lockout中 + 15℃≤temp≤35℃ + 10分経過 | lockout解除 | ✅緊急解除 |

**lockout機構**:
- `/var/lib/agriha/lockout` にUNIXタイムスタンプを書き込み
- lockout中はLayer2/Layer3の制御をスキップ（下層が上層を黙らせる原則）
- 解除条件: 10分経過 AND 温度が15-35℃の安全範囲内

**環境変数オーバーライド**: `LOCKOUT_FILE`, `LOG_FILE`, `CONF_FILE`, `UNIPI_API_URL`, `LINE_NOTIFY_TOKEN`, `CONF_DIR`

### §3.2 rule_engine.py（Layer2: ルールベース制御）

**概要**: ルールベース判断 + ピタゴラスイッチ段階制御。5分毎にcronで実行。channel_map.yaml経由でch番号を取得。

| 項目 | 内容 |
|---|---|
| **入力** | GET localhost:8080/api/sensors → indoor_temp, rainfall, wind_speed, wind_dir, solar_wm2 |
| **設定** | config/rules.yaml (pitagorasuセクション含む), config/channel_map.yaml, /var/lib/agriha/pid_override.json |
| **処理** | 優先度付きルール評価 → リレー操作 + フラグファイル管理 + ソフトウェア位置追跡 |
| **出力** | POST /api/relay/{ch}, rain_flag, wind_flag, solar_accum.json, temp_history.json, window_position.json |
| **依存** | unipi-daemon REST API, channel_config.py, window_position.py, astral (日の出/日没計算) |

**ルール優先度チェーン**:

| 優先度 | ルール | 条件 | 動作 |
|---|---|---|---|
| 1 | 降雨時全閉 | rainfall > 0 | 全窓OFF + rain_flag作成 |
| 2 | 強風方向制御 | wind_speed ≥ 5.0 m/s | 風向別片側閉鎖 + wind_flag |
| 3 | 気温急上昇 | 20分で+3℃以上 | 全窓全開 |
| 4 | 時間帯制御(6c) | 日没後〜日の出前 | 全窓閉鎖 + 夜間キャリブレーション（ピタゴラスイッチ有効時） |
| 5 | ピタゴラスイッチ段階制御(6d) | 昼間 + 上記非該当 + pitagorasu.enabled | 5段階開度制御（詳細下記） |
| 5' | PID温度制御(フォールバック) | 昼間 + pitagorasu.enabled=false | PID出力>0→全窓開, ≤0→全窓閉 |
| 6 | 日射比例灌水 | solar積算 ≥ 0.9 MJ/m² | ch4灌水60秒 |

**ピタゴラスイッチ段階制御** (Rule 6d, 2026-03-13実装):

| ステージ | 温度帯 | 南窓 | 北窓 | 名称 |
|---|---|---|---|---|
| 0 | <25℃ | 0% | 0% | closed |
| 1 | 25-27℃ | 30% | 0% | south_micro |
| 2 | 27-30℃ | 50% | 50% | both_medium |
| 3 | 30-32℃ | 80% | 80% | both_wide |
| 4 | ≥32℃ | 100% | 100% | full_open |

- **ソフトウェア位置追跡**: window_position.py でエンコーダなしモーターの推定開度を管理
- **非対称走行時間**: 開(巻き上げ)=65秒、閉(巻き下ろし)=50秒（重力影響）
- **差分制御**: 現在位置→目標位置の差分×走行時間=通電秒数
- **不感帯**: 5%以下の差分は動かさない（deadband=0.05）
- **先読み制御**: 温度トレンド+1.5℃/h→1段階先取り、+3.0℃/h→2段階先取り
- **早朝オフセット**: 5-8時は全段階を-1℃シフト
- **夜間キャリブレーション**: Rule 6cで全閉走行時間×1.1秒通電→position=0.0リセット
- **フォールバック**: `pitagorasu.enabled: false` で即座にバイナリ開閉に復帰

**PIDパラメータ** (config/rules.yaml):
- Kp=8.0, Ki=0.5, Kd=2.0, dt=600秒
- 昼間目標温度: 26.5℃（pid_override.jsonで上書き可）
- 出力範囲: 0.0-100.0%

**風向制御** (channel_map.yaml連動):
- 北風(NNW,N,NNE: dir={15,16,1,2}) → 北側窓(ch7,8)閉鎖
- 南風(SSW,S,SSE: dir={8,9,10}) → 南側窓(ch5,6)閉鎖

**灌水制御**:
- 日射積算: solar_wm2 × 600秒 / 1,000,000 = MJ/m² (10分毎加算)
- 閾値: 0.9 MJ/m²到達で ch4 灌水60秒、積算リセット
- 降雨時スキップ: rainfall ≥ 0.5 mm/h、または降雨停止後30分以内

**位置情報**: 北海道恵庭 (42.888°N, 141.603°E) — astralで日の出/日没を計算

### §3.3 forecast_engine.py（Layer3: LLM 1時間予報）

**概要**: デフォルトはNullClaw（ローカル・ゼロコスト）で向こう1時間の制御計画を生成。APIキー設定時はClaudeなどのクラウドAPIを優先使用し、API失敗・回線断時は自動でNullClawにフォールバック。毎時0分にcronで実行。高札APIの類似検索で既知パターンが3件以上あればLLMをスキップ。

| 項目 | 内容 |
|---|---|
| **入力** | sensors API, Visual Crossing天気予報, 高札API類似検索, system_prompt.txt |
| **設定** | config/system_prompt.txt, config/forecast.yaml (provider, api_key_env), .env (APIキー: オプション) |
| **処理** | 天気予報取得→類似検索→LLM判断(or skip)→計画JSON生成→PIDパラメータ変換 |
| **出力** | /var/lib/agriha/current_plan.json, pid_override.json, search_log.jsonl |
| **依存** | NullClaw (デフォルト, localhost:3001), Visual Crossing API, 高札API, unipi-daemon REST API |
| **依存(オプション)** | Claude Haiku API / OpenAI / Gemini (APIキー設定時のみ、失敗時はNullClaw) |
| **コード行数** | 456行 |

**実行フロー**:

```
1. lockoutチェック → lockout中はスキップ
2. Starlink接続チェック → ping失敗時はスキップ
3. GET /api/sensors → 現在のセンサーデータ取得
4. Visual Crossing API → 24時間天気予報 (TTL 1hキャッシュ: vc_cache.json)
5. build_search_query() → "{季節}_{時間帯}_{温度バンド}_{天気}" 生成
6. 高札API /search?q={query} → 類似過去判断を検索
7. 類似結果 ≥ 3件? → Yes: 高札結果からplan構築(source="kousatsu")
                     → No: Claude Haiku API呼び出し(source="llm")
8. convert_llm_to_pid_override() → co2_mode/humidity_max→PIDパラメータ変換
9. save_plan() → current_plan.json書き出し
10. log_search() → search_log.jsonl追記
```

**search_query形式**: `夏_午前_25-30℃_Clear`
- 季節: 月から判定（冬12-2, 春3-5, 夏6-8, 秋9-11）
- 時間帯: 早朝(<6), 午前(6-12), 午後(12-18), 夜間(≥18)
- 温度バンド: indoor_temp を5℃刻み (例: 25-30℃)
- 天気: Visual Crossing conditions フィールド

**LLM→PIDパラメータ変換**:
- co2_mode "ventilate" → co2_setpoint: 400
- co2_mode "accumulate" → co2_setpoint: 700
- humidity_max → VPD = (1 - humidity_max/100) × SVP(indoor_temp)
- SVP: Tetens式 `6.1078 × 10^(7.5T/(237.3+T))` hPa

**current_plan.json スキーマ**:
```json
{
  "generated_at": "ISO 8601",
  "valid_until": "ISO 8601 (now + 1h)",
  "source": "llm" | "kousatsu",
  "actions": [
    {"time": "ISO 8601", "relay": {"ch": 5, "value": 1, "duration_sec": 60}, "reason": "..."}
  ],
  "summary": "自然言語の計画要約"
}
```

### §3.4 plan_executor.py（計画実行）

**概要**: forecast_engine.pyが生成したcurrent_plan.jsonを読み、時刻マッチしたアクションを実行。10分毎にcronで実行。

| 項目 | 内容 |
|---|---|
| **入力** | /var/lib/agriha/current_plan.json, sensors API, flag files |
| **設定** | channel_map.yaml (WINDOW_CHANNELS, VALID_CH_MIN/MAX) |
| **処理** | 計画読込→有効期限確認→緊急温度チェック→時刻マッチ→天気フラグスキップ→リレー操作 |
| **出力** | POST /api/relay/{ch}, current_plan.json(実行結果書き戻し) |
| **依存** | unipi-daemon REST API, channel_config.py |
| **コード行数** | 284行 |

**時刻マッチング**: アクション時刻 ± 5分 (TIME_WINDOW_SEC=300) の範囲内で実行

**天気フラグスキップ**: 側窓チャンネル(ch5-8)のアクションは rain_flag/wind_flag 存在時にスキップ → `executed: "skipped_weather"`

**緊急温度制御**:
- indoor_temp > 27℃ → 全窓開放
- indoor_temp < 16℃ → 全窓閉鎖
- 緊急発動時はplan実行をスキップ

**duration_sec制限**: 最大3600秒（1時間）にクランプ

### §3.5 agriha_chat.py（Chat窓 + ダッシュボード + API）

**概要**: FastAPIアプリケーション。Chat UI、ダッシュボード、センサー/リレーAPIプロキシを統合。port 8501で稼働。

| 項目 | 内容 |
|---|---|
| **入力** | ユーザーメッセージ, unipi-daemon API, control_log.db, current_plan.json, ログファイル, フラグファイル |
| **設定** | channel_map.yaml, system_prompt.txt, api.env (ANTHROPIC_API_KEY) |
| **処理** | Chat: Claude API呼び出し。Dashboard: 各種データ集約。API: プロキシ+加工 |
| **出力** | HTML (Chat UI / Dashboard), JSON (各種API) |
| **依存** | Claude Haiku API, unipi-daemon REST API, astral, Jinja2, Chart.js (CDN) |
| **コード行数** | 599行 (+ frontend 527行) |

**APIエンドポイント一覧**:

| メソッド | パス | 機能 | 認証 |
|---|---|---|---|
| GET | `/` | Chat UI (inline HTML) | なし |
| POST | `/chat` | Claude APIプロキシ (センサー+履歴注入) | なし |
| GET | `/api/history` | 判断履歴 (control_log.db, limit 1-100) | なし |
| GET | `/api/sensors` | センサープロキシ → :8080 | なし |
| GET | `/health` | ヘルスチェック | なし |
| GET | `/dashboard` | ダッシュボードHTML (Jinja2) | なし |
| GET | `/api/plan` | 制御計画JSON (current_plan.json) | なし |
| GET | `/api/logs` | ログ末尾 (4ファイル合算, default 50行, max 200) | なし |
| GET | `/api/relay` | リレー状態プロキシ + channel_map.yamlラベル付与 | なし |
| GET | `/api/flags` | フラグ状態 (lockout/rain/wind) | なし |
| GET | `/api/channel_map` | channel_map.yaml内容 | なし |
| GET | `/api/dashboard` | 一括取得 (sensors+plan+relay+flags+logs+timestamp) | なし |

**Chat API (POST /chat)**:
1. GET /api/sensors でセンサーデータ取得
2. control_log.db から直近5件の判断履歴取得
3. system_prompt.txt 読み込み（毎リクエスト）
4. 日時+日の出/日没+時間帯をユーザーメッセージに注入
5. Claude Haiku API (claude-haiku-4-5-20251001) に送信
6. テキスト応答を返却

**ダッシュボードフロントエンド**:
- dashboard.html (69行): センサー/リレー/フラグ/タイムライン(Chart.js)/ログ
- dashboard.js (349行): 30秒ポーリング、Chart.js scatter chart
- dashboard.css (109行): レスポンシブ2カラム、センサー色分け(ok/warn/danger)

### §3.6 unipi-daemon（センサー取得 + リレー制御）

**概要**: HW抽象化デーモン。5つのasyncioタスクを並行実行。port 8080でREST API提供。

| 項目 | 内容 |
|---|---|
| **入力** | I2C (MCP23008), 1-Wire (DS18B20), UART RS485 (Misol WH65LP), GPIO (DI07-14), MQTT, UECS-CCM (UDP multicast) |
| **設定** | /etc/agriha/unipi_daemon.yaml |
| **処理** | センサー周期読取→MQTT publish、REST API→MQTT relay制御、GPIO→緊急オーバーライド |
| **出力** | REST API (JSON), MQTT topics (agriha/{house_id}/*) |
| **依存** | mosquitto MQTT broker, smbus2 (I2C), serial (UART), gpiod (GPIO) |
| **コード行数** | 2,311行 (10ファイル) |

**REST APIエンドポイント** (port 8080):

| メソッド | パス | 機能 | 認証 |
|---|---|---|---|
| POST | `/api/relay/{ch}` | リレー制御 (MQTT経由) | X-API-Key |
| GET | `/api/sensors` | センサーキャッシュ | X-API-Key |
| GET | `/api/status` | デーモン状態+lockout | X-API-Key |
| POST | `/api/emergency/clear` | lockout手動解除 | X-API-Key |

**POST /api/relay/{ch}** リクエスト:
```json
{"value": 0|1, "duration_sec": 180, "reason": "manual control"}
```
- duration_sec > 0: 自動OFFタイマー設定
- lockout中: 423 Locked Out レスポンス

**5つの並行タスク**:

| タスク | 機能 | 周期 |
|---|---|---|
| sensor_loop | DS18B20 + Misol WH65LP → MQTT publish | 10秒 |
| mqtt_loop | MQTT subscribe → relay/{ch}/set → MCP23008 制御 | 常時 |
| gpio_watch | GPIO DI07-14 エッジ検出 → 緊急オーバーライド | 常時 |
| rest_api | FastAPI REST-MQTT変換 | 常時 |
| ccm_loop | UECS-CCM UDP multicast → MQTT publish | 常時 |

**ハードウェアインターフェース**:

| IF | デバイス | 用途 |
|----|---|---|
| I2C (bus 1, addr 0x20) | MCP23008 | 8chリレー制御 (ch1=GP7〜ch8=GP0、逆配線) |
| 1-Wire (/sys/bus/w1/devices/) | DS18B20 | ハウス内温度 |
| UART RS485 (/dev/ttyUSB0, 9600bps) | Misol WH65LP | 気象 (温湿度/風速/風向/降雨/日射) |
| GPIO (/dev/gpiochip0, DI07-14) | 物理スイッチ | 緊急オーバーライド (300秒lockout) |
| UDP multicast (224.0.0.1:16520) | UECS-CCM | レガシーセンサー受信 |

### §3.7 LINE Bot（RPi直接稼働）

**概要**: RPi上のagriha-ui（FastAPI, port 8501）に統合。VPS不要。LLMはNullClaw（デフォルト）またはClaude API（APIキー設定時）。HTTPS到達はLet's Encrypt + 固定IP。

| 項目 | 内容 |
|---|---|
| **入力** | LINE Messaging API Webhook (POST /callback), unipi-daemon REST API (localhost) |
| **設定** | .env (LINE_CHANNEL_SECRET, LINE_CHANNEL_ACCESS_TOKEN, LINE_USER_ID), forecast.yaml |
| **処理** | 署名検証 → 全テキスト→LLM tool calling→REST API実行→Reply |
| **出力** | LINE応答メッセージ, POST /api/relay/{ch} (localhost) |
| **LLM** | NullClawFallbackClient（APIキーなし→NullClaw直行、あり→API優先→失敗時フォールバック） |

**主要ファイル**:
- `src/agriha/chat/app.py` L733-810: /callback エンドポイント（agriha-uiに統合）
- `src/agriha/chat/linebot_handler.py` (293行): 署名検証 + LLM tool calling + Reply/Push
- `src/agriha/control/nullclaw_proxy.py` (155行): NullClaw OpenAI互換プロキシ (port 3001)

**ツール定義** (OpenAI tools形式, linebot_handler.py):

| ツール | 機能 | パラメータ |
|---|---|---|
| get_sensors | 全センサーデータ取得（CCM+DS18B20+Misol+リレー状態） | なし |
| get_status | デーモン状態取得（リレー状態+ロックアウト+稼働時間） | なし |
| set_relay | リレーch ON/OFF制御 | channel(1-8), value(0/1), duration_sec(0=永続) |

**LLMフォールバック設計** (NullClawFallbackClient, forecast_engine.py):
- APIキー未設定 → NullClaw直行（tools除外、プロンプト埋め込み方式）
- APIキーあり → check_connectivity() → オンライン → Claude API（tool calling有効）
- API失敗 or オフライン → NullClawフォールバック（tools除外）
- 毎回ステートレス判定、回線復帰→次メッセージから自動復帰
- NullClawフォールバック時の制限: set_relay不可（読み取りのみ）

**Webhook到達方式**:

| 方式 | 条件 | URL |
|---|---|-----|
| Let's Encrypt + 固定IP | USB SIM（固定IP付きSIMカード）使用時 | `https://{固定IP}/callback` |
| 自己署名証明書 | LINE Messaging APIは自己署名をサポート（証明書登録が必要） | `https://{固定IP}/callback` |

- settings画面でWebhook URLを自動生成・表示（§3.9参照）
- LINE Developers Console に Webhook URL を設定

**旧VPS版との差分**:

| 項目 | 旧（VPS版） | 新（RPi直接版） |
|---|---|---|
| 実行場所 | VPS (Docker) | RPi (agriha-ui内) |
| LLM | Anthropic SDK直接 | NullClawFallbackClient（デフォルトNullClaw） |
| センサー取得 | WireGuard VPN経由 | localhost REST API (直接) |
| Webhook到達 | VPS固定IP | Let's Encrypt + USB SIM固定IP |
| 設定管理 | VPS上.env | RPi /opt/agriha/.env + settings UI |
| system_prompt | linebot/system_prompt.py | /etc/agriha/system_prompt.txt (共用) |
| 依存サービス | Docker, Nginx, Certbot | agriha-ui内蔵 + certbot |

### §3.8 カメラ定点撮影

### §3.9 USB SIM / APN設定UI

**概要**: settings画面に「ネットワーク設定」セクションを追加。USB SIMドングルのAPN設定、接続状態表示、LINE Webhook URL自動生成を提供。

| 項目 | 内容 |
|---|---|
| **入力** | ユーザーのAPN設定入力 |
| **設定** | NetworkManager connection profile |
| **処理** | ModemManager/NetworkManager経由でUSBドングル制御 |
| **出力** | セルラー接続確立、固定IP取得、Webhook URL表示 |
| **依存** | ModemManager, NetworkManager, usb-modeswitch |

**settings画面「ネットワーク設定」セクション**:

```
┌─────────────────────────────────────────┐
│ ネットワーク設定                          │
│                                          │
│ 接続状態: ● セルラー (SIM)  ○ WiFi  ○ 有線 │
│ 固定IP:   xxx.xxx.xxx.xxx                │
│ Webhook URL: https://xxx.xxx.xxx.xxx/callback │
│ [URLをコピー]                            │
│                                          │
│ ── APN設定 ──                            │
│ プリセット: [SORACOM ▼] [IIJmio] [手動入力] │
│                                          │
│ APN名:     [soracom.io                ] │
│ ユーザー:   [sora                      ] │
│ パスワード: [sora                       ] │
│ 認証方式:   [CHAP ▼]                     │
│                                          │
│ [保存して接続]                            │
│                                          │
│ ── LINE Bot設定 ──                       │
│ Channel Secret:  [********cret]          │
│ Access Token:    [********oken]          │
│ User ID:         [********efgh]          │
│ [保存]                                   │
│ 状態: 設定済み / 未設定                   │
│                                          │
│ ── HTTPS証明書 ──                        │
│ 証明書状態: 有効 (有効期限: 2026-06-05)   │
│ [証明書更新] [自己署名証明書で代替]        │
└─────────────────────────────────────────┘
```

**既知キャリアプリセット**:

| キャリア | APN | ユーザー | パスワード | 認証方式 |
|---|-----|---|---|---|
| SORACOM Air（デフォルト） | soracom.io | sora | sora | CHAP |
| IIJmio | iijmio.jp | mio@iij | iij | CHAP |
| 手動入力 | (ユーザー入力) | — | — | — |

> **注意**: 上記以外のキャリアをご利用の場合は「手動入力」で農家ご自身がAPN情報を入力してください。

**ModemManager/NetworkManager連携**:

```bash
# USB SIMドングル検出
mmcli -L                              # モデム一覧
mmcli -m 0                            # モデム詳細（SIM状態、信号強度）

# APN設定 → NetworkManager connection作成
nmcli connection add type gsm \
  con-name "agriha-sim" \
  ifname "*" \
  gsm.apn "soracom.io" \
  gsm.username "sora" \
  gsm.password "sora"

# 接続
nmcli connection up agriha-sim

# IP確認
nmcli device show | grep IP4.ADDRESS
```

**固定IP取得**: SIMカード契約に依存。IIJmioフルMVNO等は固定IPオプションあり。SORACOM Beamでも可能。settings画面で取得したIPをWebhook URLとして表示。

**app.pyエンドポイント追加**:

| メソッド | パス | 機能 |
|---|---|---|
| GET | `/api/network/status` | 接続状態(SIM/WiFi/有線)、固定IP、モデム情報 |
| POST | `/settings/network/apn` | APN設定保存+接続 |
| POST | `/settings/network/cert` | HTTPS証明書取得/更新 |

### §3.8 カメラ定点撮影

**概要**: agriha-capture.sh (mainブランチ)。cron定期実行でカメラ画像を撮影し、Nginx経由で /picture/ パスで配信。

| 項目 | 内容 |
|---|---|
| **入力** | USBカメラ (RPi接続) |
| **処理** | 定期撮影 → /var/www/agriha-photos/last.jpg 保存 |
| **出力** | JPEG画像ファイル |
| **備考** | v3-rebuildブランチには未移行。Nginx統合設計(report#683)でdashboardにimg表示予定 |

---

## §4 データモデル

### 4.1 データベース

#### control_log.db (判断履歴)

| パス | /var/lib/agriha/control_log.db |
|---|---|
| エンジン | SQLite3 |
| 参照元 | agriha_chat.py (GET /api/history, POST /chat) |
| 書込元 | agriha_control.py (旧LLM制御ループ、v4で整理予定) |

**テーブル: decisions**

| カラム | 型 | 内容 |
|---|-----|---|
| id | INTEGER PRIMARY KEY | 自動採番 |
| timestamp | TEXT | ISO 8601 |
| summary | TEXT | 判断要約 |
| actions_taken | TEXT | 実行アクション (JSON) |
| sensor_snapshot | TEXT | センサースナップショット (JSON) |

### 4.2 設定ファイル

| ファイル | デプロイ先 | 内容 | 参照元 |
|---|---|---|---|
| channel_map.yaml | /etc/agriha/ | ch↔機器マッピング (v2 spec) | rule_engine, plan_executor, agriha_chat, emergency_guard |
| rules.yaml | config/ (リポジトリ内) | PID/灌水/風/温度閾値 | rule_engine |
| crop_irrigation.yaml | config/ | 作物別灌水パラメータ (長ナス6ステージ) | (将来参照) |
| system_prompt.txt | /etc/agriha/ | LLMシステムプロンプト | forecast_engine, agriha_chat |
| emergency.conf | /etc/agriha/ | 緊急閾値 (temp_high=40, temp_low=5) | emergency_guard |
| unipi_daemon.yaml | /etc/agriha/ | daemon設定 (house_id, MQTT, I2C, GPIO, UART) | unipi-daemon |
| api.env | /etc/agriha/ | APIキー (ANTHROPIC_API_KEY等) | agriha_chat (EnvironmentFile) |

### 4.3 ランタイムファイル (/var/lib/agriha/)

| ファイル | 形式 | 作成元 | 参照元 | 用途 |
|---|---|---|---|---|
| lockout | Plain text (UNIX timestamp) | emergency_guard.sh | rule_engine, plan_executor, forecast_engine | 緊急ロックアウトフラグ |
| rain_flag | Empty file | rule_engine.py | plan_executor | 降雨フラグ |
| wind_flag | Empty file | rule_engine.py | plan_executor | 強風フラグ |
| current_plan.json | JSON | forecast_engine.py | plan_executor, agriha_chat | LLM制御計画 (1時間) |
| pid_override.json | JSON | forecast_engine.py | rule_engine | LLM→PIDパラメータ変換結果 |
| vc_cache.json | JSON | forecast_engine.py | forecast_engine | Visual Crossing APIキャッシュ (TTL 1h) |
| search_log.jsonl | JSONL | forecast_engine.py | — | 高札検索ログ |
| control_log.db | SQLite | agriha_control.py | agriha_chat | 判断履歴DB |
| solar_accum.json | JSON | rule_engine.py | rule_engine | 日射積算値 (灌水用) |
| temp_history.json | JSON | rule_engine.py | rule_engine | 温度履歴 (急上昇検出用、30分ローリング) |
| rain_stopped_at.json | JSON | rule_engine.py | rule_engine | 降雨停止タイムスタンプ |

### 4.4 ログファイル (/var/log/agriha/)

| ファイル | ソース | ローテーション |
|---|---|---|
| emergency.log | emergency_guard.sh | — |
| rule_engine.log | rule_engine.py | — |
| forecast_engine.log | forecast_engine.py | — |
| executor.log | plan_executor.py | — |

### 4.5 MQTTメッセージスキーマ

**センサーデータ (agriha/{house_id}/sensor/DS18B20)**:
```json
{"device_id": "28-00000de13271", "temperature_c": 22.5, "timestamp": 1740000000.0}
```

**気象データ (agriha/farm/weather/misol)**:
```json
{"temperature_c": 15.2, "humidity_pct": 65, "wind_speed_ms": 2.1, "timestamp": 1740000000.0}
```

**リレー状態 (agriha/{house_id}/relay/state)**:
```json
{"ch1": 0, "ch2": 0, "ch3": 0, "ch4": 0, "ch5": 1, "ch6": 1, "ch7": 0, "ch8": 0, "ts": 1740000000}
```

**リレー制御コマンド (agriha/{house_id}/relay/{ch}/set)**:
```json
{"value": 1, "duration_sec": 180, "reason": "manual control"}
```

---

## §5 デプロイ構成

### 5.1 systemdサービス

| サービス | ポート | デプロイ先 | 実行ユーザー | 概要 |
|---|---|---|---|---|
| unipi-daemon | 8080 | /opt/agriha/ | agriha | HW抽象化 + REST API + MQTT |
| agriha-nullclaw-proxy | 3001 | /opt/agriha/ | agriha | NullClaw OpenAI互換プロキシ (デフォルトLLM) |
| agriha-chat | 8501 | /opt/agriha-chat/ | root | WebUI + Chat + Dashboard API |
| rain_detector | — | /opt/agriha/services/ | pi | 雨検知サービス |
| uart_co2_reader | — | (リポジトリ直参照) | root | CO2センサー読取 |
| ModemManager | — | (OS標準) | root | USB SIMドングル制御 |
| certbot.timer | — | (OS標準) | root | Let's Encrypt HTTPS証明書自動更新 |

### 5.2 cronスケジュール (config/agriha.cron)

| 頻度 | スクリプト | ログ出力先 |
|---|---|---|
| `* * * * *` | emergency_guard.sh | /var/log/agriha/emergency.log |
| `*/10 * * * *` | rule_engine.py | /var/log/agriha/rule_engine.log |
| `0 * * * *` | forecast_engine.py | /var/log/agriha/forecast_engine.log |
| `*/10 * * * *` | plan_executor.py | /var/log/agriha/executor.log |

### 5.3 Nginx統合設計

**port 80 → 統合フロントエンド** (report#683 設計案):

```
http://rpi/              → agriha-chat /dashboard  (ダッシュボード)
http://rpi/chat          → agriha-chat /           (Chat窓)
http://rpi/picture/      → /var/www/agriha-photos/ (カメラ画像)
http://rpi/api/*         → agriha-chat /api/*      (ダッシュボードAPI)
http://rpi/api/unipi/*   → unipi-daemon /api/*     (直接API, API Key認証)
http://rpi/static/*      → agriha-chat /static/*   (JS/CSS)
http://rpi/health        → agriha-chat /health
```

- **LAN内HTTP**: port 80 → ダッシュボード・Chat窓（RPi Chromium kiosk表示）
- **LINE Webhook用HTTPS**: port 443 → /callback のみ。Let's Encrypt + 固定IP（USB SIM）
- **WebSocket不要**: REST + 30秒ポーリング
- **CORS不要**: Nginx統合後は同一オリジン

**Nginx HTTPS設定（LINE Webhook用）**:
```
server {
    listen 443 ssl;
    server_name _;    # 固定IPでアクセス

    ssl_certificate     /etc/letsencrypt/live/agriha/fullchain.pem;
    ssl_certificate_key /etc/letsencrypt/live/agriha/privkey.pem;

    location /callback {
        proxy_pass http://localhost:8501/callback;
    }
    location / {
        proxy_pass http://localhost:8501;
    }
}
```

### 5.4 RPiディレクトリ構成

| パス | 用途 |
|---|---|
| ~/uecs-llm/ | git clone先（デプロイ元） |
| /etc/agriha/ | 設定ファイル (channel_map.yaml, system_prompt.txt, emergency.conf, api.env, unipi_daemon.yaml) |
| /var/lib/agriha/ | ランタイムデータ (DB, plan, flags, cache) |
| /var/log/agriha/ | ログ (4ファイル) |
| /opt/agriha/ | unipi-daemon + rain_detector デプロイ先 |
| /opt/agriha-chat/ | agriha-chat デプロイ先 |
| /var/www/agriha-photos/ | カメラ画像 (Nginx配信) |

### 5.5 セットアップ (setup.sh)

`setup.sh` (128行) が冪等デプロイを提供:

1. Python venv作成 + pip install（daemon extras）
2. /etc/agriha/ ディレクトリ作成 + 設定ファイルコピー（既存は上書きしない）
3. agrihaシステムユーザー作成 + /var/lib/agriha/, /var/log/agriha/ ディレクトリ作成
4. systemdサービスインストール + enable (unipi-daemon, agriha-ui)
5. cron設定（三層制御用）
6. .env.example → .env コピー
7. Nginx設定デプロイ

**v4追加ステップ（実装予定）**:

8. USB SIM関連パッケージインストール
   ```bash
   apt install -y modem-manager network-manager usb-modeswitch
   systemctl enable ModemManager NetworkManager
   ```
9. HTTPS証明書セットアップ
   ```bash
   apt install -y certbot python3-certbot-nginx
   # 固定IP取得後に実行（setup.sh内では案内表示のみ）:
   # certbot --nginx -d {固定IP}.nip.io --non-interactive --agree-tos -m user@example.com
   # または自己署名証明書:
   # openssl req -x509 -newkey rsa:2048 -keyout /etc/agriha/ssl/key.pem -out /etc/agriha/ssl/cert.pem -days 365 -nodes
   ```
10. NullClawプロキシサービスインストール
    ```bash
    # systemd/agriha-nullclaw-proxy.service インストール + enable
    ```

**初回セットアップウィザード（構想）**:

setup.sh実行後、agriha-uiの初回アクセス時にウィザードを表示:
1. APN設定（USB SIMドングル検出→プリセット選択→接続テスト）
2. LINE Bot設定（Channel Secret/Access Token/User ID入力）
3. LINE Webhook URL表示（固定IP自動検出→URLコピー→LINE Developers Consoleへ案内）
4. テスト送信（LINE Botから「設定完了」メッセージ送信で動作確認）
5. LLMプロバイダー選択（NullClaw=デフォルト、APIキー入力でClaude等も可）

ウィザードは `/setup` エンドポイントで提供。完了後は `/dashboard` にリダイレクト。
`/var/lib/agriha/.setup_complete` フラグファイルで初回判定。

### 5.6 外部サービス依存

| サービス | 用途 | APIキー | 費用見込み |
|---|---|---|---|
| NullClaw (ローカル) | forecast_engine デフォルト | 不要 | **ゼロコスト** (箱出し即動作) |
| Claude Haiku API | forecast_engine + agriha_chat (オプション) | ANTHROPIC_API_KEY | 月数百円→自然減衰 |
| OpenAI / Gemini / Ollama | forecast_engine (オプション) | 各APIキー | 使用量に応じた費用 |
| Visual Crossing | 天気予報 (24h先) | VISUAL_CROSSING_API_KEY | 無料枠 (1000 req/day) |
| LINE Notify | 緊急通知 | LINE_NOTIFY_TOKEN | 無料 |
| LINE Messaging API | Bot対話 | LINE_CHANNEL_* | 無料枠 (200 msg/day) |

**設計思想**: デフォルト=NullClaw（ゼロコスト・オフライン・箱出し即動作）。APIキー設定時のみクラウドAPI優先。API失敗・回線断時は自動フォールバック。LLM自然減衰モデルの最終形=デフォルト状態に回帰。

### 5.7 ArSprout既存USB SIMとの互換性

**概要**: ArSprout（農研機構系統の温室環境制御装置）のオプションUSB SIMドングルを引き継いで使用できるかの整理。

**ArSproutのUSB SIM構成**:
- 一般的なUSB SIMドングル（Huawei E8372, AnyDATA W600 等）を使用
- ArSprout本体のLinux（Debian系）でNetworkManager経由で接続
- 農研機構推奨SIM: IIJmio、SORACOM Air 等

**AgriHA v4での互換性**:

| 項目 | 互換性 | 備考 |
|---|---|---|
| USBドングルハードウェア | ○ 互換 | RPi4のUSBポートにそのまま差し替え可能 |
| SIMカード | ○ 互換 | APN設定が同じなら流用可能 |
| APN設定 | ○ 移行可能 | ArSproutのNetworkManager設定を参照して手動入力、またはプリセット選択 |
| 固定IPアドレス | △ 要確認 | SIMカードに固定IPが紐づいていれば引き継がれる。キャリア契約依存 |
| ドライバー | ○ 互換 | Raspberry Pi OS（Debian系）はModemManager/usb-modeswitchを標準サポート |

**ArSproutからの移行手順**:
1. ArSproutからUSB SIMドングルを抜く
2. RPi4のUSBポートに差す
3. `mmcli -L` でモデム検出を確認
4. settings画面「ネットワーク設定」でAPN設定（ArSproutと同じ値を入力、またはプリセット選択）
5. 接続テスト → 固定IP確認
6. LINE Webhook URLをLINE Developers Consoleに設定

**注意事項**:
- ArSproutの制御PCとRPiを同時に同じSIMで使うことはできない（物理的に1枚のSIM）
- ArSproutを廃止してAgriHAに完全移行する場合にのみSIMを流用可能
- ArSproutと並行運用する場合は別途SIMカードが必要

---

<!-- §6-9: agriha_v4_spec_part2.md を参照 -->

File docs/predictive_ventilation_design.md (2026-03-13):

# 側窓予測制御 設計書

> **Version**: 2.1 | **Date**: 2026-03-13
> **Status**: **実装済み** — rule_engine.py Rule 6c/6d + window_position.py + テスト23件PASS
> **対象**: rule_engine.py (Layer 2) の Rule 6d 拡張

## 背景

現状の Layer 2 温度制御は **バイナリ開閉**（target+2℃で全開、target-1℃で全閉）のみ。
ピタゴラススイッチ（段階制御）は Layer 3 (LLM) 依存だが、LLMは1時間に1回しか判断しない。

**目標**: 温度トレンド予測に基づく段階制御を Layer 2 に降ろし、LLMの判断対象をCO2・湿度に限定する。

## 実機の物理制約

### 巻き上げモーター方式

```
リミットスイッチ(全閉) ←── モーター通電 ──→ リミットスイッチ(全開)
                     ↑
              通電秒数で開度が決まる
```

- **open_channel に N秒通電** → N秒分だけ開方向に動く
- **close_channel に N秒通電** → N秒分だけ閉方向に動く
- **リミットスイッチ**: 全開/全閉でモーター自動停止（過負荷防止）
- **エンコーダなし**: 現在位置を直接知る手段がない
- **全開走行時間**: ユーザ設定（例: 60秒）。全閉→全開に要する時間

### 開度制御の原理

巻き上げ式のため、**重力の影響で開と閉の走行時間が異なる**:
- **開（巻き上げ）**: 重力に逆らう → `open_travel_sec`（例: 65秒）
- **閉（巻き下ろし）**: 重力アシスト → `close_travel_sec`（例: 50秒）

```
開方向: 開度50% = open_travel_sec × 0.5 だけ開方向に通電
閉方向: 開度50%→0% = close_travel_sec × 0.5 だけ閉方向に通電
```

**両方とも実機でストップウォッチ計測が必須。**

### ソフトウェア位置管理

エンコーダがないため、**ソフトウェアで推定位置を管理**する必要がある：

```python
estimated_position = {
    "north": 0.0,  # 0.0=全閉, 1.0=全開
    "south": 0.0,
    "last_calibrated_at": "2026-03-13T06:00:00+09:00"
}
```

**キャリブレーション**:
- 全閉リミットスイッチ到達時 → position = 0.0 にリセット
- 全開リミットスイッチ到達時 → position = 1.0 にリセット
- 毎朝の夜間全閉（Rule 6c）後に自動キャリブレーション（閉方向に全開走行時間+余裕を通電）

## 設計方針

### ピタゴラススイッチを開度 % で定義

```
<25℃:    全閉 (0%)
25-27℃:  南 30%, 北 0%
27-30℃:  南 50%, 北 50%
30-32℃:  南 80%, 北 80%
>32℃:    全開 (100%)
```

### 差分制御（現在位置 → 目標位置）

5分ごとの rule_engine 実行で:
1. ピタゴラスステージから **目標開度** を算出
2. 推定現在位置との **差分** を計算
3. 差分 × 全開走行時間 = **通電秒数** を決定
4. `duration_sec` 付きでリレーON → 自動OFF

```python
# 例: 現在 south=0.3 (30%), 目標 south=0.5 (50%)
delta = 0.5 - 0.3  # = +0.2 (開方向)
duration = delta * open_travel_sec  # = 0.2 × 65 = 13秒（巻き上げなので open_travel 使用）
→ open_channel ON, duration_sec=13

# 例: 現在 south=0.5 (50%), 目標 south=0.3 (30%)
delta = 0.5 - 0.3  # = 0.2 (閉方向)
duration = delta * close_travel_sec  # = 0.2 × 50 = 10秒（巻き下ろしなので close_travel 使用）
→ close_channel ON, duration_sec=10
```

### 先読み制御（Predictive Opening）

既存の `compute_temperature_trend()` を活用。温度上昇速度に応じて目標開度を嵩上げ。

```
trend > +3.0℃/h → 2段階先取り（急上昇）
trend > +1.5℃/h → 1段階先取り（通常上昇）
trend ≤ +1.5℃/h → 現在ステージのまま
```

### 早朝オフセット

既存 `early_morning_offset: -1.0` を活用。5-8時は全段階を-1℃シフト。

## 実装設計

### 新モジュール: `window_position.py`

推定位置の管理を専用モジュールに分離。

```python
"""window_position.py — 側窓推定位置管理

エンコーダなしの巻き上げモーターの開度をソフトウェアで追跡する。
"""

import json
from datetime import datetime
from pathlib import Path
from zoneinfo import ZoneInfo

_JST = ZoneInfo("Asia/Tokyo")
DEFAULT_POSITION_PATH = "/var/lib/agriha/window_position.json"

def load_position(path: str = DEFAULT_POSITION_PATH) -> dict:
    """推定位置を読み込む。ファイルなし時は全閉(0.0)を返す。"""
    try:
        return json.loads(Path(path).read_text())
    except (FileNotFoundError, json.JSONDecodeError):
        return {
            "north": 0.0,
            "south": 0.0,
            "last_calibrated_at": None,
            "last_updated_at": None,
        }

def save_position(pos: dict, path: str = DEFAULT_POSITION_PATH) -> None:
    """推定位置を保存する。"""
    pos["last_updated_at"] = datetime.now(tz=_JST).isoformat()
    Path(path).write_text(json.dumps(pos, ensure_ascii=False, indent=2))

def update_position(
    pos: dict,
    group_name: str,
    direction: str,  # "open" | "close"
    duration_sec: float,
    open_travel_sec: float,
    close_travel_sec: float,
) -> dict:
    """通電実績から推定位置を更新する。

    開と閉で走行時間が異なる（重力の影響）:
    - 開（巻き上げ）: 重力に逆らう → open_travel_sec（長い）
    - 閉（巻き下ろし）: 重力アシスト → close_travel_sec（短い）
    """
    key = "north" if "北" in group_name else "south"
    if direction == "open":
        delta = duration_sec / open_travel_sec
        pos[key] = min(1.0, pos[key] + delta)
    else:
        delta = duration_sec / close_travel_sec
        pos[key] = max(0.0, pos[key] - delta)
    return pos

def calibrate_closed(pos: dict, group_name: str) -> dict:
    """全閉キャリブレーション（リミットスイッチ到達後に呼ぶ）"""
    key = "north" if "北" in group_name else "south"
    pos[key] = 0.0
    pos["last_calibrated_at"] = datetime.now(tz=_JST).isoformat()
    return pos

def calibrate_open(pos: dict, group_name: str) -> dict:
    """全開キャリブレーション"""
    key = "north" if "北" in group_name else "south"
    pos[key] = 1.0
    pos["last_calibrated_at"] = datetime.now(tz=_JST).isoformat()
    return pos

def compute_move(
    current_pos: float,
    target_pos: float,
    open_travel_sec: float,
    close_travel_sec: float,
    deadband: float = 0.05,
) -> tuple[str | None, float]:
    """現在位置→目標位置の移動を計算する。

    開と閉で走行時間が異なる（重力の影響）:
    - 開方向: open_travel_sec を使用（巻き上げ、重力に逆らうので遅い）
    - 閉方向: close_travel_sec を使用（巻き下ろし、重力アシストで速い）

    Returns:
        (direction, duration_sec): ("open", 12.0) or ("close", 8.0) or (None, 0)
    """
    delta = target_pos - current_pos
    if abs(delta) < deadband:
        return None, 0  # 不感帯内 → 動かさない
    if delta > 0:
        return "open", delta * open_travel_sec
    else:
        return "close", abs(delta) * close_travel_sec
```

### 新関数: `_compute_pitagorasu_stage()`

```python
def _compute_pitagorasu_stage(
    temp: float,
    trend: float | None,
    hour: int,
    early_offset: float = -1.0,
    stages: list[dict] | None = None,
    predictive_cfg: dict | None = None,
) -> dict:
    """ピタゴラススイッチの段階と目標開度を返す。

    Returns:
        {
            "stage": 0-4,
            "stage_name": str,
            "south_target": 0.0-1.0,  # 目標開度
            "north_target": 0.0-1.0,
            "reason": str,
        }
    """
    # デフォルトステージ定義
    if stages is None:
        stages = [
            {"max_temp": 25.0, "south": 0.0, "north": 0.0, "name": "closed"},
            {"max_temp": 27.0, "south": 0.3, "north": 0.0, "name": "south_micro"},
            {"max_temp": 30.0, "south": 0.5, "north": 0.5, "name": "both_medium"},
            {"max_temp": 32.0, "south": 0.8, "north": 0.8, "name": "both_wide"},
            {"max_temp": 999,  "south": 1.0, "north": 1.0, "name": "full_open"},
        ]

    # 早朝オフセット
    offset = early_offset if 5 <= hour < 8 else 0.0

    # 先読み補正
    predictive_bonus = 0.0
    if trend is not None and trend > 0:
        p = predictive_cfg or {}
        rapid = p.get("rapid_trend_threshold", 3.0)
        mild = p.get("mild_trend_threshold", 1.5)
        if trend > rapid:
            predictive_bonus = p.get("rapid_bonus", 2.0)
        elif trend > mild:
            predictive_bonus = p.get("mild_bonus", 1.0)

    effective_temp = temp + predictive_bonus + offset

    # 段階判定
    for i, s in enumerate(stages):
        if effective_temp < s["max_temp"]:
            return {
                "stage": i,
                "stage_name": s["name"],
                "south_target": s["south"],
                "north_target": s["north"],
                "reason": f"T_eff={effective_temp:.1f}℃ → {s['name']} "
                          f"(S:{s['south']:.0%} N:{s['north']:.0%})",
            }

    # フォールバック（全開）
    last = stages[-1]
    return {
        "stage": len(stages) - 1,
        "stage_name": last["name"],
        "south_target": last["south"],
        "north_target": last["north"],
        "reason": f"T_eff={effective_temp:.1f}℃ → {last['name']} (フォールバック)",
    }
```

### Rule 6d 変更箇所 (evaluate_rules 内)

```python
if not layer3_active:
    if indoor_temp is not None:
        trend = compute_temperature_trend(temp_history)
        hour = now.hour
        pitagorasu = _compute_pitagorasu_stage(
            indoor_temp, trend, hour,
            early_offset=temp_cfg.get("early_morning_offset", -1.0),
            stages=pitagorasu_cfg.get("stages"),
            predictive_cfg=pitagorasu_cfg.get("predictive"),
        )
        triggered_rules.append(f"pitagorasu_stage_{pitagorasu['stage']}")
        logger.info("Rule 6d: %s", pitagorasu["reason"])

        # 推定位置を読み込み
        win_pos = load_position()
        open_travel = pitagorasu_cfg.get("open_travel_sec", 65)
        close_travel = pitagorasu_cfg.get("close_travel_sec", 50)
        deadband = pitagorasu_cfg.get("deadband", 0.05)

        for g in groups:
            if _group_acted(g):
                continue
            is_south = "南" in g["name"]
            key = "south" if is_south else "north"
            current = win_pos.get(key, 0.0)
            target = pitagorasu[f"{key}_target"]

            direction, dur = compute_move(current, target, open_travel, close_travel, deadband)
            if direction is None:
                logger.info("Rule 6d: %s 不感帯内 (%.0f%%→%.0f%%) → 維持",
                            g["name"], current*100, target*100)
                continue

            if direction == "open":
                relay_actions.append((g["open_channel"], 1, int(dur)))
                relay_actions.append((g["close_channel"], 0, None))
            else:
                relay_actions.append((g["close_channel"], 1, int(dur)))
                relay_actions.append((g["open_channel"], 0, None))

            logger.info("Rule 6d: %s %s %.0f%%→%.0f%% (%s %d秒)",
                        g["name"], direction, current*100, target*100,
                        direction, int(dur))

            # 推定位置を更新
            update_position(win_pos, g["name"], direction, dur, open_travel, close_travel)

        save_position(win_pos)
```

### 夜間キャリブレーション

Rule 6c（夜間全閉）実行時に、全閉走行時間+10%の余裕を持って閉方向に通電し、
リミットスイッチ到達後にソフトウェア位置をリセット:

```python
# Rule 6c 変更箇所
if nighttime:
    triggered_rules.append("nighttime_close")
    close_travel = pitagorasu_cfg.get("close_travel_sec", 50)
    calibration_dur = int(close_travel * 1.1)  # +10%余裕（閉方向なのでclose_travel使用）
    for g in groups:
        if not _group_acted(g):
            relay_actions.append((g["close_channel"], 1, calibration_dur))
            relay_actions.append((g["open_channel"], 0, None))
            calibrate_closed(win_pos, g["name"])
    save_position(win_pos)
    logger.info("Rule 6c: 夜間全閉 + キャリブレーション (%d秒)", calibration_dur)
```

## rules.yaml 追加設定

```yaml
temperature:
  # 既存
  target_day: 26.0
  target_night: 17.0
  margin_open: 2.0
  margin_close: 1.0
  attention_temp: 30.0
  emergency_temp: 32.0
  early_morning_offset: -1.0

  # 新規: ピタゴラススイッチ段階制御
  pitagorasu:
    enabled: true
    open_travel_sec: 65        # 全閉→全開の走行時間（秒）★実測必須★ 重力に逆らうので遅い
    close_travel_sec: 50       # 全開→全閉の走行時間（秒）★実測必須★ 重力アシストで速い
    deadband: 0.05             # 5%以下の差分は動かさない（モーター保護）
    stages:
      - {max_temp: 25.0, south: 0.0, north: 0.0, name: "closed"}
      - {max_temp: 27.0, south: 0.3, north: 0.0, name: "south_micro"}
      - {max_temp: 30.0, south: 0.5, north: 0.5, name: "both_medium"}
      - {max_temp: 32.0, south: 0.8, north: 0.8, name: "both_wide"}
      - {max_temp: 999,  south: 1.0, north: 1.0, name: "full_open"}
    predictive:
      mild_trend_threshold: 1.5    # ℃/h — 1段階先読み
      rapid_trend_threshold: 3.0   # ℃/h — 2段階先読み
      mild_bonus: 1.0              # ℃ equivalent
      rapid_bonus: 2.0             # ℃ equivalent
```

## system_prompt.txt からの削減

ピタゴラススイッチがLayer 2に降りるので、system_prompt.txtから以下を**簡素化**:

- Rule 2 (ピタゴラススイッチ段階制御) → 「Layer 2で自動段階制御中。LLMは監視のみ。異常時のみ介入」
- Rule 7 (早朝先行換気) → 「Layer 2で自動実施」

**LLMに残す判断**:
- Rule 3: 湿度優先（朝6時台、湿度85%超 → 温度より換気優先）
- Rule 4: CO2パルス換気（300ppm以下 → 全窓全開5-10分）
- 天気予報との複合判断（曇り→換気不要の判断等）
- pid_override.json による目標温度変更（今後実装）

## 位置ずれの蓄積対策

ソフトウェア推定位置は通電秒数の積算なので、誤差が蓄積する。対策:

| 対策 | タイミング | 方法 |
|---|---|---|
| **夜間キャリブレーション** | 毎晩 Rule 6c | 全閉方向に travel_time×1.1 秒通電→position=0.0 |
| **全開時キャリブレーション** | stage 4 (≥32℃) | 全開方向に travel_time×1.1 秒通電→position=1.0 |
| **リミットスイッチ到達** | 全閉/全開通過 | duration > remaining_distance の場合、自動クランプ |
| **定期リセット** | 朝6時 | 夜間全閉後なので position=0.0 を再確認 |

## テスト計画

| テストケース | 入力 | 期待出力 |
|---|---|---|
| 24℃安定, pos=0% | temp=24, trend=0, pos=0.0 | 動作なし（既に全閉） |
| 26℃上昇中, pos=0% | temp=26, trend=+2.0, pos=0.0 | south open 30秒 (0→50%, 先読み+1℃→27℃相当→stage2) |
| 28℃安定, pos=50% | temp=28, trend=0, pos=0.5 | 動作なし（目標50%=現在50%、不感帯内） |
| 28℃→31℃, pos=50% | temp=31, trend=+1.0, pos=0.5 | south/north open 18秒 (50%→80%) |
| 33℃, pos=80% | temp=33, pos=0.8 | south/north open 12秒+余裕 (80%→100%, キャリブレーション) |
| 下降26℃, pos=50% | temp=26, trend=-2.0, pos=0.5 | south close 12秒 (50%→30%), north close 30秒 (50%→0%) |
| 早朝6時25℃, pos=0% | temp=25, trend=+1.5, hour=6 | south open 18秒 (0→30%, offset-1→24℃+bonus1→25℃→stage1) |
| 夜間全閉 | nighttime=true, pos=0.7 | close 66秒 (travel_time×1.1), pos→0.0 |
| 不感帯 | target=0.5, current=0.48 | 動作なし (delta=0.02 < deadband=0.05) |

## 影響範囲

| ファイル | 変更内容 |
|---|---|
| `window_position.py` (新規) | 推定位置管理モジュール |
| `rule_engine.py` | `_compute_pitagorasu_stage()` 新規、Rule 6d/6c書き換え |
| `config/rules.yaml` | `pitagorasu` セクション追加 |
| `config/system_prompt.txt` | Rule 2, 7 を簡素化 |
| `tests/control/test_rule_engine.py` | 段階制御テスト9件以上追加 |
| `tests/control/test_window_position.py` (新規) | 位置管理ユニットテスト |

## リスク

| リスク | 対策 |
|---|---|
| 段階制御が攻撃的すぎる | `pitagorasu.enabled: false` で即座に旧ロジック復帰 |
| 先読みが過剰開放 | `predictive.mild_bonus` / `rapid_bonus` を0にすれば先読み無効 |
| Layer 3との競合 | `layer3_active` チェックは既存のまま。Layer 3有効時はLayer 2段階制御もスキップ |
| 位置推定ずれ蓄積 | 夜間キャリブレーション+全開時キャリブレーション+不感帯 |
| travel_time設定ミス | 初回デプロイ時に実機で全閉→全開・全開→全閉の両方をストップウォッチ計測 |
| 開閉速度の非対称 | open_travel_sec / close_travel_sec を個別設定。重力による差を吸収 |
| モーター過負荷 | deadband=5%で頻繁な微調整を防止。最小通電≒deadband×close_travel=2.5秒 |

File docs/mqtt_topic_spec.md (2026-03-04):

# MQTT Topic Specification for Greenhouse IoT System

> **Version**: 1.1.0
> **Last Updated**: 2026-02-21
> **System**: unipi-agri-ha (Greenhouse Monitoring & Control)
> **Protocol**: MQTT v3.1.1
> **Broker**: Mosquitto (port 1883)

---

## Table of Contents

1. [Overview](#overview)
2. [Topic Naming Convention](#topic-naming-convention)
3. [House ID Naming Convention](#house-id-naming-convention)
4. [JSON Payload Specification](#json-payload-specification)
5. [Sensor Types](#sensor-types)
6. [Device Types](#device-types)
7. [Actuator Types](#actuator-types)
8. [QoS Recommendations](#qos-recommendations)
9. [Telegraf Configuration Notes](#telegraf-configuration-notes)
10. [Examples](#examples)

---

## Overview

This document defines the MQTT topic structure and payload format for the greenhouse IoT system. The system uses a unified MQTT-based architecture for sensor data collection, actuator control, and alert notifications.

**Key Principles**:
- **JSON-only payloads**: All messages use JSON format (no plain values)
- **Hierarchical topics**: Topics follow a greenhouse/house/entity structure
- **ISO 8601 timestamps**: All timestamps use ISO 8601 format with timezone
- **UTF-8 encoding**: All string data uses UTF-8 encoding

---

## Topic Naming Convention

### 1. Sensor Data Topics

#### Single-Value Sensors
For sensors that report a single measurement value:

```
greenhouse/{house_id}/sensor/{type}
```

**Examples**:
- `greenhouse/h1/sensor/temperature`
- `greenhouse/h2/sensor/humidity`
- `greenhouse/h3/sensor/co2`

#### Multi-Value Sensors (Device-Based)
For sensors that report multiple values (e.g., SHT31 reports both temperature and humidity):

```
greenhouse/{house_id}/sensor/{device}/state
```

**Examples**:
- `greenhouse/h1/sensor/sht/state` (temperature + humidity)
- `greenhouse/h1/sensor/scd/state` (CO2 + temperature + humidity)
- `greenhouse/h1/sensor/bmp280/state` (pressure + temperature)

### 2. Actuator Control Topics

#### Command Topic (Control)
For sending commands to actuators:

```
greenhouse/{house_id}/actuator/{type}/command
```

**Examples**:
- `greenhouse/h1/actuator/irrigation/command`
- `greenhouse/h1/actuator/ventilation/command`
- `greenhouse/h1/actuator/heater/command`

#### State Topic (Feedback)
For actuator state reporting:

```
greenhouse/{house_id}/actuator/{type}/state
```

**Examples**:
- `greenhouse/h1/actuator/irrigation/state`
- `greenhouse/h1/actuator/ventilation/state`
- `greenhouse/h1/actuator/heater/state`

### 3. Node Status Topics

For node health monitoring and Last Will Testament (LWT):

```
greenhouse/{house_id}/status
```

**Example**:
- `greenhouse/h1/status` (node alive/dead)

### 4. Alert Topics

For alert notifications (sensor anomalies, system errors):

```
greenhouse/{house_id}/alert
```

**Example**:
- `greenhouse/h1/alert` (high temperature, sensor failure)

### 5. System-Wide Topics

For system-level messages that affect all houses:

```
greenhouse/system/{type}
```

**Examples**:
- `greenhouse/system/alert` (global alerts)
- `greenhouse/system/config` (configuration updates)
- `greenhouse/system/ota` (OTA update notifications)

---

## House ID Naming Convention

House IDs follow a simple numeric pattern:

| House ID | Description |
|---|---|
| `h1` | House 1 |
| `h2` | House 2 |
| `h3` | House 3 |
| ... | ... |
| `h99` | House 99 |

**Format**: `h{N}` where N is an integer (1-99)

**Special Cases**:
- `test` - Test environment nodes
- `lab` - Laboratory/development nodes

---

## JSON Payload Specification

### Sensor Data Payload

#### Single-Value Sensor

```json
{
  "value": 25.5,
  "unit": "℃",
  "sensor_type": "temperature",
  "house_id": "h1",
  "source": "pico_node_01",
  "timestamp": "2026-02-07T12:00:00+09:00"
}
```

**Required Fields**:
- `value` (number): Sensor reading value
- `sensor_type` (string): Type of sensor (see [Sensor Types](#sensor-types))
- `house_id` (string): House identifier
- `source` (string): Node/device identifier
- `timestamp` (string): ISO 8601 timestamp with timezone

**Optional Fields**:
- `unit` (string): Unit of measurement (e.g., "℃", "%", "ppm")
- `location` (string): Physical location within house (e.g., "indoor", "outdoor")
- `room` (string): Room number (e.g., "1", "2")
- `region` (string): Region within room (e.g., "north", "south")
- `order` (string): Sensor order/position

#### Multi-Value Sensor (Device State)

```json
{
  "temperature": 25.5,
  "humidity": 65.0,
  "unit_temperature": "℃",
  "unit_humidity": "%",
  "device": "sht31",
  "house_id": "h1",
  "source": "pico_node_01",
  "timestamp": "2026-02-07T12:00:00+09:00"
}
```

**Required Fields**:
- One or more measurement fields (e.g., `temperature`, `humidity`, `co2`)
- `device` (string): Device model/type
- `house_id` (string): House identifier
- `source` (string): Node/device identifier
- `timestamp` (string): ISO 8601 timestamp

**Optional Fields**:
- `unit_{field_name}` (string): Unit for each measurement field

### Actuator Command Payload

```json
{
  "command": 1,
  "timestamp": "2026-02-07T12:00:00+09:00"
}
```

**Required Fields**:
- `command` (integer): Command value
  - `0` = OFF
  - `1` = ON
- `timestamp` (string): ISO 8601 timestamp

**Optional Fields**:
- `duration` (integer): Duration in seconds (for timed operations)
- `source` (string): Command originator (e.g., "node-red", "ha", "manual")

### Actuator State Payload

```json
{
  "state": "ON",
  "timestamp": "2026-02-07T12:00:00+09:00"
}
```

**Required Fields**:
- `state` (string): Current state ("ON" or "OFF")
- `timestamp` (string): ISO 8601 timestamp

### Node Status Payload

```json
{
  "status": "online",
  "uptime": 3600,
  "ip": "192.168.1.100",
  "rssi": -65,
  "timestamp": "2026-02-07T12:00:00+09:00"
}
```

**Required Fields**:
- `status` (string): Node status ("online" or "offline")
- `timestamp` (string): ISO 8601 timestamp

**Optional Fields**:
- `uptime` (integer): Uptime in seconds
- `ip` (string): Node IP address
- `rssi` (integer): WiFi signal strength (dBm)
- `firmware_version` (string): Firmware version

### Alert Payload

```json
{
  "alert_level": "warning",
  "message": "High temperature: 38.5℃ (threshold: 35℃)",
  "sensor_type": "temperature",
  "value": 38.5,
  "threshold": 35.0,
  "house_id": "h1",
  "source": "node-red",
  "timestamp": "2026-02-07T12:00:00+09:00"
}
```

**Required Fields**:
- `alert_level` (string): Alert severity
  - `"info"` - Informational
  - `"warning"` - Warning condition
  - `"critical"` - Critical condition
- `message` (string): Human-readable alert message
- `timestamp` (string): ISO 8601 timestamp

**Optional Fields**:
- `sensor_type` (string): Related sensor type
- `value` (number): Current value that triggered alert
- `threshold` (number): Threshold value
- `house_id` (string): Affected house
- `source` (string): Alert originator

---

## Sensor Types

Standard sensor types for single-value sensor topics (`greenhouse/{house_id}/sensor/{type}`):

| Sensor Type | Description | Unit | Typical Range |
|---|---|---|---|
| `temperature` | Air temperature | ℃ | -10 to 50 |
| `humidity` | Relative humidity | % | 0 to 100 |
| `co2` | CO2 concentration | ppm | 400 to 3000 |
| `illuminance` | Light intensity | lx | 0 to 100000 |
| `wind_speed` | Wind speed | m/s | 0 to 20 |
| `soil_moisture` | Soil moisture | % | 0 to 100 |
| `pressure` | Atmospheric pressure | hPa | 950 to 1050 |
| `solar_radiation` | Solar radiation | W/m² | 0 to 1200 |
| `water_pressure` | Water pressure | kPa | 0 to 500 |
| `rainfall` | Rainfall detection | binary | 0 or 1 |

---

## Device Types

Standard device types for multi-value sensor topics (`greenhouse/{house_id}/sensor/{device}/state`):

| Device Type | Description | Measurements | Interface | Models |
|---|---|---|---|---|
| `sht` | Temperature & Humidity | temperature, humidity | I2C | SHT30, SHT31, SHT40, SHT41 |
| `scd` | CO2, Temperature & Humidity | co2, temperature, humidity | I2C | SCD30, SCD40, SCD41 |
| `bmp280` | Pressure & Temperature | pressure, temperature | I2C | BMP280 |
| `solar` | Solar Radiation | value | ADC | Custom |
| `water_pressure` | Water Pressure | value | ADC | Custom |
| `cdm7160` | CO2 Sensor | co2 | UART | CDM7160 |
| `k30` | CO2 Sensor | co2 | UART | K30 |
| `drainage` | Drainage Monitor | volume, ec | GPIO + ADC | Custom |
| `rain` | Rain Detector | detected | GPIO | DFRobot SEN0575 |

---

## Actuator Types

Standard actuator types for control topics:

| Actuator Type | Description | Command Values | State Values |
|---|---|---|---|
| `irrigation` | Irrigation valve/pump | 0 (OFF), 1 (ON) | "ON", "OFF" |
| `ventilation` | Ventilation fan | 0 (OFF), 1 (ON) | "ON", "OFF" |
| `heater` | Heating system | 0 (OFF), 1 (ON) | "ON", "OFF" |
| `cooling` | Cooling system | 0 (OFF), 1 (ON) | "ON", "OFF" |
| `lighting` | Supplemental lighting | 0 (OFF), 1 (ON) | "ON", "OFF" |
| `curtain` | Shade curtain | 0 (OPEN), 1 (CLOSE) | "OPEN", "CLOSE" |
| `relay` | Generic relay | 0 (OFF), 1 (ON) | "ON", "OFF" |

---

## QoS Recommendations

Quality of Service (QoS) levels for different message types:

| Message Type | Topic Pattern | QoS | Retain | Rationale |
|---|---|-----|---|---|
| Sensor Data | `greenhouse/{house_id}/sensor/**` | **0** | No | High frequency, loss acceptable |
| Actuator Command | `greenhouse/{house_id}/actuator/*/command` | **1** | No | Must be delivered, no duplicates needed |
| Actuator State | `greenhouse/{house_id}/actuator/*/state` | **1** | Yes | Must be delivered, retain for status queries |
| Node Status | `greenhouse/{house_id}/status` | **1** | Yes | Must be delivered, retain for monitoring |
| Alert | `greenhouse/{house_id}/alert` | **1** | Yes | Must be delivered, retain for review |
| System Message | `greenhouse/system/**` | **1** | No | Must be delivered to all subscribers |

**QoS Level Definitions**:
- **QoS 0** (At most once): Fire-and-forget, no acknowledgment
- **QoS 1** (At least once): Acknowledged delivery, may duplicate
- **QoS 2** (Exactly once): Guaranteed delivery, no duplicates (not used in this system)

---

## Telegraf Configuration Notes

### Critical Requirements

1. **JSON Format Required**
   - Telegraf's MQTT consumer plugin requires `data_format = "json"`
   - Plain text values (e.g., `"25.5"`) will be rejected
   - All payloads must be valid JSON objects

   ```toml
   [[inputs.mqtt_consumer]]
     data_format = "json"
     json_string_fields = []  # Parse all fields as their natural types
   ```

2. **Tag Extraction**
   - Use `tag_keys` to extract fields for InfluxDB tags
   - Common tags: `house_id`, `sensor_type`, `source`, `device`

   ```toml
   [[inputs.mqtt_consumer]]
     tag_keys = ["house_id", "sensor_type", "source", "device"]
   ```

3. **Field Filtering**
   - Use `json_query` to extract nested values if needed
   - Use `fieldpass` to include only specific fields in InfluxDB

4. **Topic Wildcards**
   - Single-level wildcard: `+` (e.g., `greenhouse/+/sensor/temperature`)
   - Multi-level wildcard: `#` (e.g., `greenhouse/#` for all topics)

   ```toml
   [[inputs.mqtt_consumer]]
     topics = [
       "greenhouse/+/sensor/#",
       "greenhouse/+/actuator/+/state",
       "greenhouse/+/alert"
     ]
   ```

5. **Timestamp Parsing**
   - Telegraf can parse ISO 8601 timestamps from JSON `timestamp` field
   - Configure timezone if needed

   ```toml
   [[inputs.mqtt_consumer]]
     json_time_key = "timestamp"
     json_time_format = "2006-01-02T15:04:05Z07:00"
   ```

### Example Telegraf Configuration

```toml
[[inputs.mqtt_consumer]]
  servers = ["tcp://localhost:1883"]
  topics = ["greenhouse/#"]
  qos = 0
  data_format = "json"

  # Tag extraction
  tag_keys = ["house_id", "sensor_type", "source", "device"]

  # Timestamp
  json_time_key = "timestamp"
  json_time_format = "2006-01-02T15:04:05Z07:00"

  # Measurement name
  name_override = "greenhouse_data"

[[outputs.influxdb_v2]]
  urls = ["http://localhost:8086"]
  token = "$INFLUX_TOKEN"
  organization = "agri-ha"
  bucket = "sensor_data"
```

---

## Examples

### Example 1: Temperature Sensor Data

**Topic**: `greenhouse/h1/sensor/temperature`

**Payload**:
```json
{
  "value": 25.5,
  "unit": "℃",
  "sensor_type": "temperature",
  "house_id": "h1",
  "source": "pico_node_01",
  "location": "indoor",
  "timestamp": "2026-02-07T12:00:00+09:00"
}
```

**Publishing (mosquitto_pub)**:
```bash
mosquitto_pub -h localhost -t "greenhouse/h1/sensor/temperature" -m '{
  "value": 25.5,
  "unit": "℃",
  "sensor_type": "temperature",
  "house_id": "h1",
  "source": "pico_node_01",
  "timestamp": "2026-02-07T12:00:00+09:00"
}'
```

### Example 2: SHT31 Sensor (Multi-Value)

**Topic**: `greenhouse/h1/sensor/sht/state`

**Payload**:
```json
{
  "temperature": 25.5,
  "humidity": 65.0,
  "unit_temperature": "℃",
  "unit_humidity": "%",
  "device": "sht31",
  "house_id": "h1",
  "source": "pico_node_01",
  "timestamp": "2026-02-07T12:00:00+09:00"
}
```

### Example 3: Irrigation Control

**Command Topic**: `greenhouse/h1/actuator/irrigation/command`

**Command Payload (Turn ON)**:
```json
{
  "command": 1,
  "duration": 600,
  "source": "node-red",
  "timestamp": "2026-02-07T12:00:00+09:00"
}
```

**State Topic**: `greenhouse/h1/actuator/irrigation/state`

**State Payload (Feedback)**:
```json
{
  "state": "ON",
  "timestamp": "2026-02-07T12:00:05+09:00"
}
```

### Example 4: High Temperature Alert

**Topic**: `greenhouse/h1/alert`

**Payload**:
```json
{
  "alert_level": "warning",
  "message": "High temperature: 38.5℃ (threshold: 35℃)",
  "sensor_type": "temperature",
  "value": 38.5,
  "threshold": 35.0,
  "house_id": "h1",
  "source": "node-red",
  "timestamp": "2026-02-07T14:30:00+09:00"
}
```

### Example 5: Node Status (LWT)

**Topic**: `greenhouse/h1/status`

**Online Payload**:
```json
{
  "status": "online",
  "uptime": 3600,
  "ip": "192.168.1.100",
  "rssi": -65,
  "firmware_version": "1.0.0",
  "timestamp": "2026-02-07T12:00:00+09:00"
}
```

**Offline Payload (Last Will Testament)**:
```json
{
  "status": "offline",
  "timestamp": "2026-02-07T12:00:00+09:00"
}
```

### Example 6: MicroPython Publishing (Pico)

```python
from mqtt_mgr import create_greenhouse_mqtt
import time

# Initialize MQTT manager
mqtt = create_greenhouse_mqtt(node_id="pico_node_01", broker="192.168.15.14")
mqtt.connect()

# Publish temperature data
payload = {
    "value": 25.5,
    "unit": "℃",
    "sensor_type": "temperature",
    "house_id": "h1",
    "source": "pico_node_01",
    "timestamp": time.strftime("%Y-%m-%dT%H:%M:%S+09:00")
}

mqtt.publish("greenhouse/h1/sensor/temperature", payload, qos=0)
```

### Example 7: Home Assistant MQTT Sensor

```yaml
mqtt:
  sensor:
    - name: "Greenhouse H1 Temperature"
      state_topic: "greenhouse/h1/sensor/temperature"
      unit_of_measurement: "℃"
      device_class: temperature
      value_template: "{{ value_json.value | float }}"
      unique_id: "greenhouse_h1_temperature"
```

---

## unipi-daemon Topics (agriha/ namespace)

unipi-daemon (Pi Lite) が publish する独自トピック。`greenhouse/` ネームスペースとは別系統。

### Topic Structure

```
agriha/{house_id}/sensor/DS18B20           ... 1-Wire温度センサー
agriha/farm/weather/misol                  ... Misol WH65LP 外気象
agriha/{house_id}/ccm/sensor/{ccm_type}    ... CCM 内気象センサー
agriha/{house_id}/ccm/actuator/{ccm_type}  ... CCM アクチュエータ状態
agriha/{house_id}/ccm/weather/{ccm_type}   ... CCM 外気象（ArSprout経由）
agriha/{house_id}/ccm/other/{ccm_type}     ... CCM 未分類
agriha/{house_id}/relay/{ch}/set           ... リレー制御コマンド (REST API → MQTT)
agriha/{house_id}/relay/state              ... リレー全チャンネル状態
agriha/{house_id}/emergency                ... 緊急オーバーライド通知
```

### CCM Sensor Types

| ccm_type | Description | Unit |
|---|---|---|
| `InAirTemp` | Indoor air temperature | ℃ |
| `InAirHumid` | Indoor air humidity | % |
| `InAirCO2` | Indoor CO2 | ppm |
| `SoilTemp` | Soil temperature | ℃ |
| `SoilEC` | Soil electrical conductivity | mS/cm |
| `SoilWC` | Soil water content | % |
| `InRadiation` | Indoor solar radiation | W/m² |
| `Pulse` | Pulse counter | count |
| `InAirHD` | Indoor humidity deficit | hPa |
| `InAirAbsHumid` | Indoor absolute humidity | g/m³ |
| `InAirDP` | Indoor dew point | ℃ |

### CCM Payload Example

```json
{
  "ccm_type": "InAirTemp",
  "value": 23.5,
  "room": 1,
  "region": 11,
  "order": 1,
  "priority": 1,
  "level": "S",
  "source_ip": "192.168.1.70",
  "timestamp": "2026-02-21T14:05:54.748325+00:00"
}
```

### Misol Weather Payload Example

```json
{
  "wind_dir_deg": 270,
  "temperature_c": 3.1,
  "humidity_pct": 88,
  "wind_speed_ms": 1.12,
  "gust_speed_ms": 2.24,
  "rainfall_mm": 0.0,
  "uv_wm2": 0.0,
  "light_lux": 0.0,
  "pressure_hpa": 1014.3,
  "battery_low": false,
  "timestamp": 1771680000.0
}
```

### QoS for agriha/ Topics

| Topic Pattern | QoS | Retain |
|---|-----|---|
| `agriha/{id}/sensor/DS18B20` | 1 | Yes |
| `agriha/farm/weather/misol` | 1 | Yes |
| `agriha/{id}/ccm/#` | 0 | Yes |
| `agriha/{id}/relay/{ch}/set` | 1 | No |
| `agriha/{id}/relay/state` | 1 | Yes |
| `agriha/{id}/emergency` | 1 | Yes |

### REST API → MQTT Mapping

| REST Endpoint | MQTT Topic | Direction |
|---|---|---|
| `GET /api/sensors` | subscribes `agriha/{id}/sensor/#`, `weather/misol`, `ccm/#` | MQTT→REST |
| `POST /api/relay/{ch}` | publishes `agriha/{id}/relay/{ch}/set` | REST→MQTT |
| `GET /api/status` | reads relay state + lockout | internal |

---

## Version History

| Version | Date | Changes |
|---|---|---|
| 1.1.0 | 2026-02-21 | Add unipi-daemon topics (agriha/ namespace): CCM, Misol, relay, emergency |
| 1.0.0 | 2026-02-07 | Initial specification |

---

## References

- [MQTT Version 3.1.1 Specification](http://docs.oasis-open.org/mqtt/mqtt/v3.1.1/os/mqtt-v3.1.1-os.html)
- [Telegraf MQTT Consumer Plugin](https://github.com/influxdata/telegraf/tree/master/plugins/inputs/mqtt_consumer)
- [Home Assistant MQTT Integration](https://www.home-assistant.io/integrations/mqtt/)
- [ISO 8601 Date and Time Format](https://en.wikipedia.org/wiki/ISO_8601)

---

**Document Owner**: unipi-agri-ha Project Team
**Contact**: See repository documentation

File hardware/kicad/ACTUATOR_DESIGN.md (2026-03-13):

# Pico 2 W アクチュエータノード基板 設計ドキュメント

**バージョン**: 1.0
**作成日**: 2026-02-08
**ターゲット**: Raspberry Pi Pico 2 W
**用途**: 4チャンネルリレー駆動（電磁弁・換気扇制御）

---

## 1. 概要

本基板は、Raspberry Pi Pico 2 W を使用した4チャンネルリレー駆動基板である。温室制御盤内に設置し、WiFi経由でMQTT通信を行い、電磁弁・換気扇等のAC負荷を制御する。

### 主な特徴
- **4chリレー駆動**: 電磁弁、換気扇、灌水バルブ等を制御
- **WiFi通信**: Pico 2 W の無線LANでMQTT通信
- **USB給電**: USB 5V給電（1ポートで動作）
- **フォトカプラ絶縁**: AC負荷との電気的絶縁による安全設計
- **制御盤内設置**: 温室制御盤内の限られたスペースに対応

### 使用想定
- 温室制御システムのアクチュエータノード
- 制御盤内設置（センサーノードは圃場分散配置）
- WiFi通信範囲内（制御盤は建物近傍）
- Home Assistant / Node-RED からの制御

---

## 2. ピンアサイン表

### 完全ピン配置（40ピン）

| GPIO | 機能 | 本基板用途 | 接続先 | 備考 |
|---|---|---|---|---|
| GP0 | UART0 TX | NC | - | 将来拡張用に予約 |
| GP1 | UART0 RX | NC | - | 将来拡張用に予約 |
| GP2 | GPIO | NC | - | 将来拡張用に予約 |
| GP3 | GPIO | NC | - | 将来拡張用に予約 |
| GP4 | I2C0 SDA | NC | - | 将来拡張用に予約 |
| GP5 | I2C0 SCL | NC | - | 将来拡張用に予約 |
| GP6 | I2C1 SDA | NC | - | 将来拡張用に予約 |
| GP7 | I2C1 SCL | NC | - | 将来拡張用に予約 |
| GP8 | UART1 TX | NC | - | 将来拡張用に予約 |
| GP9 | UART1 RX | NC | - | 将来拡張用に予約 |
| **GP10** | **GPIO** | **リレーCH0 制御** | フォトカプラU1 入力 | **Irri（灌水バルブ）** |
| **GP11** | **GPIO** | **リレーCH1 制御** | フォトカプラU2 入力 | **Valve（汎用バルブ）** |
| **GP12** | **GPIO** | **リレーCH2 制御** | フォトカプラU3 入力 | **VenFan（換気扇）** |
| **GP13** | **GPIO** | **リレーCH3 制御** | フォトカプラU4 入力 | **Relay（汎用リレー）** |
| GP14 | GPIO | NC | - | 将来拡張用に予約 |
| GP15 | GPIO | NC | - | 将来拡張用に予約 |
| GP16 | SPI0 MISO | NC | - | 将来拡張用に予約 |
| GP17 | SPI0 CS | NC | - | 将来拡張用に予約 |
| GP18 | SPI0 SCK | NC | - | 将来拡張用に予約 |
| GP19 | SPI0 MOSI | NC | - | 将来拡張用に予約 |
| GP20 | GPIO | NC | - | 将来拡張用に予約 |
| GP21 | GPIO | NC | - | 将来拡張用に予約 |
| GP22 | PWM | NC | - | 将来拡張用に予約 |
| GP23 | GPIO | NC | - | 将来拡張用に予約 |
| GP24 | GPIO | NC | - | 将来拡張用に予約 |
| GP25 | GPIO | NC | - | Pico内蔵LED共用（使用注意） |
| GP26 | ADC0 | NC | - | 将来拡張用に予約 |
| GP27 | ADC1 | NC | - | 将来拡張用に予約 |
| GP28 | ADC2 | NC | - | 将来拡張用に予約 |
| GND | Power | **GND** | 全回路共通 | - |
| 3V3 | Power | **3.3V** | Pico内部電源 | フォトカプラ1次側 |
| VSYS | Power | **5V In** | USB供給 | リレー・フォトカプラ2次側 |
| VBUS | Power | NC | - | 未使用 |

### ⚠️ 重要な設計判断
- **GP10-GP13**: config_actuator.py の RELAY_PINS と一致
- **RELAY_ACTIVE_HIGH = True**: GPIO HIGH = リレーON（config_actuator.py と一致）
- **actuator_control.py との相違**: デフォルトの active_low=True とは逆極性。初期化時に `active_low=False` を指定する必要あり

---

## 3. 回路ブロック図

```
                    ┌──────────────────────────────────────┐
                    │  Raspberry Pi Pico 2 W               │
                    │                                      │
    USB 5V ─────────┤ VSYS (5V)                            │
                    │  └─ Onboard LDO → 3V3 (3.3V)        │
                    │                                      │
                    │  GP10 ────┐                          │
                    │  GP11 ────┤                          │
                    │  GP12 ────┤  GPIO Output (3.3V)      │
                    │  GP13 ────┘                          │
                    │                                      │
                    │  WiFi Module (内蔵)                  │
                    └──────────────────────────────────────┘
                             │ │ │ │
                             │ │ │ │
            ┌────────────────┘ │ │ └────────────────┐
            │   ┌──────────────┘ └──────────────┐   │
            │   │   ┌──────────────────────┐    │   │
            │   │   │                      │    │   │
            ▼   ▼   ▼                      ▼    ▼   ▼
    ┌───────────────────────────────────────────────────┐
    │        フォトカプラ絶縁段 (U1-U4: PC817)          │
    │                                                   │
    │   [1次側: 3.3V]          [2次側: 5V]             │
    │                                                   │
    │   GPIO ──[R9]──>LED      TRout──>MOSFET Gate     │
    │   GND  <───────LED       TRout──[R8]──>GND       │
    │                                                   │
    └───────────────────────────────────────────────────┘
                             │ │ │ │
                             │ │ │ │
            ┌────────────────┘ │ │ └────────────────┐
            │   ┌──────────────┘ └──────────────┐   │
            │   │   ┌──────────────────────┐    │   │
            │   │   │                      │    │   │
            ▼   ▼   ▼                      ▼    ▼   ▼
    ┌───────────────────────────────────────────────────┐
    │       MOSFET駆動段 (Q1-Q4: 2N7002)                │
    │                                                   │
    │   5V ──[D1]──> Drain ──> リレーコイル(K1-K4)     │
    │                Source ──> GND                     │
    │   Gate <─ PC817                                   │
    │   Gate ─[R5]─> GND (10kΩ プルダウン)             │
    │                                                   │
    └───────────────────────────────────────────────────┘
                             │ │ │ │
                             │ │ │ │
            ┌────────────────┘ │ │ └────────────────┐
            │   ┌──────────────┘ └──────────────┐   │
            │   │   ┌──────────────────────┐    │   │
            │   │   │                      │    │   │
            ▼   ▼   ▼                      ▼    ▼   ▼
    ┌───────────────────────────────────────────────────┐
    │         リレー段 (K1-K4: 5V SPDT リレー)          │
    │                                                   │
    │   Coil: 5V, 50mA                                  │
    │   Contacts: SPDT, 10A @ 250VAC                    │
    │                                                   │
    │   K1: Irri   (灌水バルブ)                         │
    │   K2: Valve  (汎用バルブ)                         │
    │   K3: VenFan (換気扇)                             │
    │   K4: Relay  (汎用リレー)                         │
    │                                                   │
    └───────────────────────────────────────────────────┘
                             │ │ │ │
                             │ │ │ │
                             ▼ ▼ ▼ ▼
    ┌───────────────────────────────────────────────────┐
    │       出力端子台 (J3-J6: 3ピン端子台)             │
    │                                                   │
    │   NO (Normally Open)                              │
    │   COM (Common)                                    │
    │   NC (Normally Closed)                            │
    │                                                   │
    └───────────────────────────────────────────────────┘
                             │ │ │ │
                             │ │ │ │
                             ▼ ▼ ▼ ▼
                        AC 100V 負荷
               (電磁弁, 換気扇, 灌水ポンプ等)

    ┌───────────────────────────────────────────────────┐
    │         インジケータLED (LED1-LED4)                │
    │                                                   │
    │   5V ──[R1]──> LED ──> GND                        │
    │   (MOSFET Drain から分岐)                         │
    │                                                   │
    └───────────────────────────────────────────────────┘
```

---

## 4. リレー駆動回路詳細

### 4.1 なぜMOSFET（2N7002）か？

**選定理由:**
1. **3.3Vゲート駆動可能**: Vgs(th) = 1.0V (typ), 2.5V (max)
   - 3.3V駆動で十分なドレイン電流（50mA以上）を確保
2. **ドレイン電流**: Ids = 300mA (max)
   - リレーコイル（50mA）の6倍の余裕
3. **小型パッケージ**: SOT-23
   - 基板面積の削減
4. **入手性**: JLCPCB標準部品（C8545）
   - 組立コスト削減

**代替候補:**
- BSS138 (C193658): Vgs(th)=0.8V, Ids=200mA（余裕小）
- AO3400A (C20917): Vgs(th)=0.5V, Ids=5.8A（オーバースペック）

### 4.2 なぜフォトカプラ（PC817）か？

**選定理由:**
1. **電気的絶縁**: AC100V負荷と制御回路を完全分離
   - 絶縁耐圧: 5000Vrms (IEC60747-5-5規格)
   - 感電・ノイズ混入を防止
2. **安全規格**: UL認定、VDE認定
   - 産業用途で実績あり
3. **電流伝達比**: CTR = 50-600%
   - 入力電流10mA → 出力電流 5-60mA（MOSFETゲート駆動に十分）
4. **入手性**: JLCPCB標準部品（C66723）

**代替候補:**
- TLP291 (シャープ): CTR高いが高価
- 4N35 (TI): 古い世代、入手性やや劣る

### 4.3 プルダウン抵抗（10kΩ）の役割

**必要性:**
- Pico起動時（GPIO未初期化時）にMOSFETゲートがフローティング
- フローティング状態ではリレーが不定動作（誤ONの危険）
- 10kΩプルダウンでゲートを強制的にGNDに引く → 起動時リレーOFF保証

**抵抗値計算:**
- ゲートリーク電流: < 1nA (2N7002データシート)
- プルダウン電流: 3.3V / 10kΩ = 0.33mA（無視できる）

### 4.4 フライバックダイオード（1N4148）

**必要性:**
- リレーコイルはインダクタ（L成分）
- OFF時に逆起電力（-V = L × dI/dt）が発生 → MOSFETを破壊
- フライバックダイオードで逆起電力を5V電源に還流

**選定理由:**
- 高速スイッチング: trr = 4ns
- 小型: DO-35 or SOD-323
- 入手性: JLCPCB標準部品（C81598）

---

## 5. BOM（Bill of Materials）

| RefDes | 品名 | 値 | フットプリント | JLCPCB品番 | 数量 | 備考 |
|---|---|-----|---|---|---|---|
| U1 | Raspberry Pi Pico 2 W | - | - | - | 1 | 別途調達 |
| Q1-Q4 | N-ch MOSFET | 2N7002 | SOT-23 | C8545 | 4 | Vgs(th)=1.0V, Ids=300mA |
| D1-D4 | Switching Diode | 1N4148 | SOD-323 | C81598 | 4 | フライバック保護 |
| U2-U5 | Photocoupler | PC817 | DIP-4 | C66723 | 4 | CTR=50-600%, 5000Vrms絶縁 |
| R1-R4 | 抵抗 | 100Ω | 0603 | C23140 | 4 | MOSFETゲート抵抗 |
| R5-R8 | 抵抗 | 10kΩ | 0603 | C25804 | 4 | MOSFETゲートプルダウン |
| R9-R12 | 抵抗 | 330Ω | 0603 | C23138 | 4 | LED電流制限 (10mA) |
| R13-R16 | 抵抗 | 330Ω | 0603 | C23138 | 4 | フォトカプラ入力電流制限 |
| LED1-LED4 | LED | 赤色 | 0603 | C72038 | 4 | 状態表示（Vf=2.0V, If=10mA） |
| C1 | 電解コンデンサ | 100μF/10V | Φ5mm | C134493 | 1 | 5V電源平滑（リレー突入電流対策） |
| C2 | セラミックコンデンサ | 100nF | 0603 | C14663 | 1 | 3.3V電源デカップリング |
| J1, J2 | ピンヘッダ | 1×20P 2.54mm | - | C492404 | 2 | Pico接続用 |
| J3-J6 | 端子台 | 3P 5.08mm | - | C8465 | 4 | リレー出力（NO/COM/NC） |
| J7 | 端子台 | 2P 5.08mm | - | C8430 | 1 | 外部5V電源入力（オプション） |
| K1-K4 | 5V SPDTリレー | HK19F-DC5V-SHG | - | C35449 | 4 | Coil:5V/50mA, Contact:10A/250VAC |

**合計コンポーネント数:**
- 部品総数: 46点（U1, U2-U5, Q1-Q4, K1-K4, R1-R16, D1-D4, LED1-LED4, C1-C2, J1-J7）

**合計コスト概算:**
- 基板製造: ¥500（JLCPCB 10枚/10営業日）
- 部品代: ¥500（SMD部品 + リレー + 端子台）
- 組立代: ¥800（JLCPCB SMT組立）
- Pico 2 W: ¥1,500
- ケース: ¥300（タカチ SW-65B 相当）
- **合計: ¥3,600/棟**

---

## 6. 電力計算

### 6.1 リレーコイル消費電力

**1チャンネルあたり:**
- リレーコイル: 5V × 50mA = 0.25W
- インジケータLED: 3.3V × 10mA = 0.033W
- フォトカプラLED: 3.3V × 10mA = 0.033W
- 合計: **0.316W/ch**

**4チャンネル同時ON時:**
- リレー: 0.25W × 4 = 1.0W
- LED: 0.033W × 4 = 0.132W
- フォトカプラ: 0.033W × 4 = 0.132W
- Pico 2 W本体: 0.5W（WiFi通信時）
- **合計: 1.76W**

### 6.2 USB給電要件

**USB 2.0規格:**
- 標準: 500mA @ 5V = 2.5W
- USB 3.0: 900mA @ 5V = 4.5W

**余裕率:**
- 消費電力: 1.76W
- USB 2.0供給: 2.5W
- **余裕: 0.74W（29.6%）** → **OK**

**突入電流対策:**
- リレー駆動時の突入電流: < 100mA/ch（リレーコイルのL成分により緩和）
- C1（100μF）で突入電流を平滑化

---

## 7. 安全設計

### 7.1 電気的絶縁

**フォトカプラによる絶縁:**
- 1次側（制御側）: 3.3V（Pico GPIO）
- 2次側（負荷側）: 5V（リレー駆動）
- AC負荷: 100V（端子台経由）

**絶縁耐圧:**
- PC817: 5000Vrms（IEC60747-5-5規格）
- クリアランス: 基板設計で4mm以上確保（IEC61010-1規格）

### 7.2 起動時安全

**プルダウン抵抗による起動時OFF保証:**
- MOSFETゲート: 10kΩプルダウン
- Pico起動時（GPIO未初期化）: ゲート電圧 = 0V → MOSFET OFF → リレーOFF
- ファームウェア初期化: `machine.Pin(10, machine.Pin.OUT, value=0)` → 明示的にOFF

### 7.3 逆起電力保護

**フライバックダイオード:**
- リレーコイルOFF時の逆起電力を5V電源に還流
- MOSFETのドレイン-ソース間電圧 (Vds) を保護

### 7.4 過電流保護

**USBポリスイッチ:**
- Pico 2 W基板にはUSBポリスイッチ（復帰型ヒューズ）が実装済み
- 過電流時（> 500mA）に自動遮断

---

## 8. 既存設計との対応

### 8.1 config_actuator.py との整合性

| 項目 | config_actuator.py | 本基板設計 | 整合性 |
|---|---|---|---|
| GPIO番号 | RELAY_PINS = [10, 11, 12, 13] | GP10-GP13 | ✅ 一致 |
| 極性 | RELAY_ACTIVE_HIGH = True | HIGH = ON | ✅ 一致 |
| CCMマッピング | Irri→0, Valve→1, VenFan→2, Relay→3 | CH0-CH3 | ✅ 一致 |

### 8.2 actuator_control.py との注意点

**不整合:**
- `actuator_control.py`: デフォルト `active_low=True`
- 本基板: `RELAY_ACTIVE_HIGH = True`（HIGH = ON）

**対応方法:**
```python
from actuator_control import RelayController

# 【重要】active_low=False を明示的に指定
relays = RelayController(
    pins=[10, 11, 12, 13],
    active_low=False,  # ← この基板はactive_high設計
    names=['Irri', 'Valve', 'VenFan', 'Relay']
)
```

**推奨:**
- `config_actuator.py` と `actuator_control.py` の初期化コードを統一
- `active_low=False` をデフォルト引数として明記

---

## 9. 配線仕様

### 9.1 AC負荷配線

**電磁弁（AC100V, 5VA）:**
- 電流: 5VA / 100V = 50mA
- 電線: VVF 1.6mm（屋内配線規格）
- 最大長: 50m（電圧降下 < 2V）

**換気扇（AC100V, 50W）:**
- 電流: 50W / 100V = 0.5A
- 電線: VVF 1.6mm
- 最大長: 30m（電圧降下 < 2V）

### 9.2 USB給電配線

**USB延長ケーブル:**
- 規格: USB 2.0 Type-A オス - マイクロUSB
- 最大長: 3m（USB規格推奨）
- 給電: 制御盤内AC100V → USB ACアダプタ（5V/1A）

---

## 10. 部品コスト概算

| 項目 | 単価 | 数量 | 小計 |
|---|---|---|---|
| Raspberry Pi Pico 2 W | ¥1,500 | 1 | ¥1,500 |
| 基板製造（JLCPCB） | ¥50 | 1 | ¥50 |
| SMD部品（抵抗・コンデンサ・LED） | ¥20 | 1 | ¥20 |
| MOSFET（2N7002） | ¥10 | 4 | ¥40 |
| ダイオード（1N4148） | ¥5 | 4 | ¥20 |
| フォトカプラ（PC817） | ¥30 | 4 | ¥120 |
| リレー（HK19F-DC5V-SHG） | ¥100 | 4 | ¥400 |
| 端子台（5.08mm） | ¥30 | 5 | ¥150 |
| ピンヘッダ | ¥20 | 2 | ¥40 |
| ケース（タカチ SW-65B） | ¥300 | 1 | ¥300 |
| USB ACアダプタ（5V/1A） | ¥500 | 1 | ¥500 |
| **合計** | - | - | **¥3,140** |

**量産効果（10台）:**
- 基板製造: ¥500 / 10 = ¥50/枚
- 部品一括購入: 約10%削減
- **量産単価: ¥2,900/台**

---

## 11. 回路図チェックリスト

### 設計確認事項
- [x] GP10-GP13がconfig_actuator.pyと一致
- [x] RELAY_ACTIVE_HIGH = Trueと一致（HIGH = ON）
- [x] フォトカプラ絶縁設計（5000Vrms）
- [x] MOSFETプルダウン（起動時OFF保証）
- [x] フライバックダイオード（逆起電力保護）
- [x] インジケータLED（状態表示）
- [x] 電源平滑コンデンサ（突入電流対策）
- [x] USB給電要件（< 2.5W）
- [x] JLCPCB標準部品で統一（低コスト）

### 安全性確認
- [x] AC100V - 制御回路間の絶縁（フォトカプラ）
- [x] 起動時リレーOFF保証（プルダウン）
- [x] 過電流保護（USBポリスイッチ）
- [x] 基板クリアランス（4mm以上）

### ソフトウェア整合性
- [x] config_actuator.py との整合性確認
- [x] actuator_control.py の active_low=False 指定注意喚起

---

## 12. 次ステップ

1. **KiCad回路図作成**: 本ドキュメントをベースに回路図を作成
2. **基板レイアウト**: AC配線と制御回路の物理的分離を考慮
3. **試作発注**: JLCPCB 5枚発注（約¥500、5営業日）
4. **実機検証**: 電磁弁・換気扇の実負荷試験
5. **ファームウェア統一**: config_actuator.py と actuator_control.py の不整合解消

---

**作成者**: 足軽2号（Ashigaru-2）
**レビュー**: 未実施
**承認**: 未実施

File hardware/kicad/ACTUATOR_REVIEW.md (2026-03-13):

# Pico 2 W アクチュエータ基板 回路図検証レポート

**検証日**: 2026-02-08
**検証者**: 足軽3号（Ashigaru-3）
**対象**: actuator_board.kicad_sch Rev 1.0
**参照**: ACTUATOR_DESIGN.md

---

## 検証サマリ

| 項目 | 状態 | 詳細 |
|---|---|---|
| 1. GPIO assignments (GP10-13) | ⚠️ **要改善** | ピン定義はあるが配線記述なし |
| 2. リレー駆動回路完全性 | ❌ **不完全** | リレー(K1-K4)のシンボルなし |
| 3. BOM整合性 | ❌ **不一致** | RefDes不整合、抵抗値不一致、欠落部品多数 |
| 4. 安全設計 | ✅ **適合** | プルダウン・フライバック設計は正しい |
| 5. 電源系統 | ⚠️ **不完全** | シンボルはあるが配線なし |
| 6. コンポーネント数 | ❌ **不足** | 全41点中31点のみ（リレー4点、ピンヘッダ2点が欠落） |
| 7. ピンヘッダ配置 | ❌ **未配置** | J1, J2のインスタンスなし |
| 8. 配線完成度 | ❌ **0%** | wireセクションが存在しない |

**総合判定**: ⚠️ **回路図は「シンボル配置フェーズ」で配線未完成。設計書と整合性があるが実装不可。**

---

## 1. GPIO assignments 検証（GP10-13）

### 1.1 回路図のピン定義

**U1 (Raspberry_Pi_Pico) のピン定義:**
```
Line 38-53: GP10, GP11, GP12, GP13 の4ピンが定義済み
  GP10 (pin 14): at -15.24 10.16
  GP11 (pin 15): at -15.24 7.62
  GP12 (pin 16): at -15.24 5.08
  GP13 (pin 17): at -15.24 2.54
```

**config_actuator.py との整合性:**
```python
RELAY_PINS = [10, 11, 12, 13]  # ✅ 一致
CCM_TO_RELAY_MAP = {
    'Irri': 0,    # GP10 → J3 (Relay_ch0_Irrigation)
    'Valve': 1,   # GP11 → J4 (Relay_ch1_Valve)
    'VenFan': 2,  # GP12 → J5 (Relay_ch2_Fan)
    'Relay': 3    # GP13 → J6 (Relay_ch3_Spare)
}
```

### 1.2 問題点

❌ **配線記述なし**: 回路図には `wire`, `junction`, `no_connect` セクションが存在しない
- GP10-GP13からフォトカプラU2-U5への接続が記述されていない
- シンボル座標は設定されているが、ピン間の電気的接続が未定義

**影響**: KiCad上で「Electrical Rules Check (ERC)」を実行するとエラー多数発生

### 1.3 判定

⚠️ **要改善**: ピン定義は正しいが、配線作業が必要

**推奨対応:**
1. GP10 → R13 → U2 pin1 (フォトカプラ入力)
2. GP11 → R14 → U3 pin1
3. GP12 → R15 → U4 pin1
4. GP13 → R16 → U5 pin1

---

## 2. リレー駆動回路完全性（4チャンネル）

### 2.1 チャンネル構成確認

| ch | GPIO | フォトカプラ | ゲート抵抗 | プルダウン | MOSFET | フライバック | LED | LED抵抗 | 出力端子台 | リレー |
|----|---|---|---|---|---|---|-----|---|---|---|
| 0 | GP10 | U2 (PC817) | R1 (100Ω) | R5 (10kΩ) | Q1 (2N7002) | D1 (1N4148) | LED1 | R9 (330Ω) | J3 | **❌ K1なし** |
| 1 | GP11 | U3 (PC817) | R2 (100Ω) | R6 (10kΩ) | Q2 (2N7002) | D2 (1N4148) | LED2 | R10 (330Ω) | J4 | **❌ K2なし** |
| 2 | GP12 | U4 (PC817) | R3 (100Ω) | R7 (10kΩ) | Q3 (2N7002) | D3 (1N4148) | LED3 | R11 (330Ω) | J5 | **❌ K3なし** |
| 3 | GP13 | U5 (PC817) | R4 (100Ω) | R8 (10kΩ) | Q4 (2N7002) | D4 (1N4148) | LED4 | R12 (330Ω) | J6 | **❌ K4なし** |

### 2.2 欠落コンポーネント

❌ **リレー (K1-K4) のシンボルなし**
- 回路図に HK19F-DC5V-SHG リレーのシンボル定義がない
- DESIGN.md BOM には記載あり（4個、JLCPCB C35449）

**回路図で定義すべき記号:**
```
(symbol
  (lib_id "Relay:RELAY_SPDT")
  (at X Y 0)
  (property "Reference" "K1")
  (property "Value" "HK19F-DC5V-SHG")
)
```

### 2.3 配線トポロジーの不備

❌ **MOSFET Drain → リレーコイル接続なし**
- Q1-Q4 のドレイン(pin 3)から J3-J6 への配線が未記述
- リレーコイルを駆動する回路ループが成立しない

**正しい接続（設計書 §3 ブロック図より）:**
```
VSYS (5V) → K1 Coil+ → Q1 Drain → Q1 Source → GND
          ↓
          D1 (flyback, K1 Coil+ → Coil-)
```

### 2.4 判定

❌ **不完全**: リレー本体が欠落、配線未完成

**推奨対応:**
1. K1-K4 のシンボル追加（lib: Relay:RELAY_SPDT or Relay:G5LE-1-DC5）
2. 各チャンネルの配線完成:
   - VSYS → K{n} Coil+ → Q{n} Drain
   - Q{n} Source → GND
   - D{n} Cathode(K) → VSYS, Anode(A) → Q{n} Drain

---

## 3. BOM整合性

### 3.1 RefDes不整合

| 設計書 | 回路図 | 不整合 |
|---|---|---|
| U0 (Pico 2 W) | U1 | ⚠️ 設計書はU0、回路図はU1 |
| U1-U4 (PC817) | U2-U5 | ❌ 1つズレ |

**原因**: 設計書は Pico を U0 とカウント、回路図は U1 から開始

**推奨**: 統一ルールを決定（Pico = U0 または U1）

### 3.2 抵抗値不整合

| RefDes | 設計書 | 回路図 | 用途 | 整合性 |
|---|---|---|---|---|
| R1-R4 | 330Ω | **100Ω** | 設計書: LED電流制限 / 回路図: ゲート抵抗 | ❌ 不一致 |
| R5-R8 | 10kΩ | 10kΩ | プルダウン | ✅ 一致 |
| R9-R12 | 330Ω | 330Ω | 設計書: フォトカプラ入力 / 回路図: LED電流制限 | ⚠️ 用途混乱 |
| R13-R16 | - | 330Ω | フォトカプラ入力電流制限 | ❌ 設計書BOMに記載なし |

**問題分析:**
- 設計書のBOM表では R1-R4 を「LED電流制限 (330Ω)」と記載
- しかし回路図では R1-R4 = 100Ω、R9-R12 = 330Ω、R13-R16 = 330Ω
- 実際の用途:
  - R13-R16 (330Ω): フォトカプラ入力電流制限（GPIO → フォトカプラLED）
  - R1-R4 (100Ω): フォトカプラ出力 → MOSFETゲート抵抗（プルアップ代わり？）
  - R9-R12 (330Ω): インジケータLED電流制限

### 3.3 設計書BOMに欠落している部品

❌ **R13-R16 (330Ω)**: フォトカプラ入力電流制限抵抗（回路図にあり、BOMなし）

**影響**: 部品発注時に4個不足 → 基板組立不可

### 3.4 回路図に欠落している部品

❌ **K1-K4 (HK19F-DC5V-SHG)**: リレー本体（BOMにあり、回路図なし）
❌ **J1, J2 (1×20P ピンヘッダ)**: Pico接続用（BOMにあり、回路図にインスタンスなし）

### 3.5 判定

❌ **不一致**: 抵抗値・RefDes・欠落部品の3つの問題あり

**推奨対応:**
1. 設計書BOM修正: R13-R16 を追加、R1-R4の値を100Ωに変更
2. 回路図修正: K1-K4, J1, J2 を追加
3. RefDes統一: U0/U1問題を解決

---

## 4. 安全設計

### 4.1 プルダウン抵抗（起動時OFF保証）

✅ **適合**: R5-R8 (10kΩ) が Q1-Q4 のゲートをGNDにプルダウン
- 回路図 line 552, 722, 893, 1064 で確認
- Pico起動時（GPIO未初期化時）にMOSFETゲート電圧 = 0V → リレーOFF保証

**計算確認:**
- Vgs = 3.3V × (10kΩ / (10kΩ + 100Ω)) ≒ 3.27V（フォトカプラON時）
- Vgs = 0V（起動時、フローティング防止）

### 4.2 フライバックダイオード（逆起電力保護）

✅ **適合**: D1-D4 (1N4148) が各リレーコイルに並列
- 回路図 line 589, 760, 931, 1102 で確認
- 極性: Cathode(K)→VSYS, Anode(A)→MOSFET Drain（正しい向き）

**動作確認:**
- リレーOFF時: コイルの逆起電力を5V電源に還流
- MOSFETのVds破壊を防止

### 4.3 判定

✅ **適合**: 起動時安全・逆起電力保護ともに設計意図通り

---

## 5. 電源系統

### 5.1 電源ピン定義

✅ **定義済み**:
- Line 54-57: 3V3 (pin 36)
- Line 58-61: VSYS (pin 39)
- Line 62-65: VBUS (pin 40)

### 5.2 平滑コンデンサ

✅ **適切**:
- C1 (line 1178): 100μF/10V 電解コンデンサ（VSYS-GND、突入電流吸収）
- C2 (line 1197): 100nF セラミックコンデンサ（3V3-GND、デカップリング）

### 5.3 外部5V入力端子

✅ **定義済み**:
- J7 (line 1215): Conn_01x02 "Power_5V_In"（USB給電が不足時の外部DC5V入力用）

### 5.4 問題点

❌ **配線なし**: 電源ピンとコンデンサ、各ICの電源ピンへの配線が未記述

**必要な配線:**
- VSYS → C1+ → K1-K4 Coil+, U2-U5 pin4 (フォトカプラ2次側 Vcc)
- 3V3 → C2+ → R13-R16 → U2-U5 pin1 (フォトカプラ1次側)
- GND → C1-, C2-, Q1-Q4 Source, U2-U5 pin2 (1次側GND), U2-U5 pin3 (2次側GND)

### 5.5 判定

⚠️ **不完全**: シンボルは正しいが配線未完成

---

## 6. コンポーネント数

### 6.1 期待値（DESIGN.md BOM §5より）

| 種類 | 数量 | 合計 |
|---|---|---|
| U0 (Pico 2 W) | 1 | 1 |
| Q1-Q4 (MOSFET) | 4 | 4 |
| D1-D4 (Diode) | 4 | 4 |
| U1-U4 (Photocoupler) | 4 | 4 |
| R1-R4, R5-R8, R9-R12 | 12 | 12 |
| LED1-LED4 | 4 | 4 |
| C1, C2 | 2 | 2 |
| J1, J2 (Pin header) | 2 | 2 |
| J3-J6 (Terminal block) | 4 | 4 |
| J7 (Power input) | 1 | 1 |
| K1-K4 (Relay) | 4 | 4 |
| **合計** | - | **42** |

**訂正**: R13-R16 を追加すると R系は16個 → 合計46個

### 6.2 実際（actuator_board.kicad_sch）

| 種類 | RefDes | 数量 |
|---|---|---|
| Raspberry Pi Pico | U1 | 1 |
| Photocoupler | U2-U5 | 4 |
| MOSFET | Q1-Q4 | 4 |
| Diode | D1-D4 | 4 |
| LED | LED1-LED4 | 4 |
| Resistor | R1-R16 | 16 |
| Capacitor | C1, C2 | 2 |
| Terminal block | J3-J7 | 5 |
| **合計** | - | **40** |

### 6.3 欠落コンポーネント

❌ **K1-K4 (Relay)**: 4個欠落
❌ **J1, J2 (Pin header)**: 2個欠落

### 6.4 判定

❌ **不足**: 46個中40個（87%）、リレーとピンヘッダが未配置

---

## 7. ピンヘッダ配置

### 7.1 設計書の要求

**DESIGN.md BOM §5:**
- J1, J2: ピンヘッダ 1×20P 2.54mm (JLCPCB C492404) × 2個
- 用途: Raspberry Pi Pico 2 W の40ピンをブレッドボードライクに接続

### 7.2 回路図の状況

❌ **インスタンスなし**:
- `(symbol (lib_id "Connector:Raspberry_Pi_Pico") (at 50 100 0))` のみ
- J1, J2 のシンボルインスタンスが存在しない
- 回路図内の `Conn_01x02` (J7), `Conn_01x03` (J3-J6) のみ

### 7.3 影響

**基板製造不可**: Picoを実装するためのピンヘッダパッドがPCBレイアウトで配置できない

### 7.4 判定

❌ **未配置**: J1, J2 を追加する必要あり

**推奨対応:**
```
(symbol
  (lib_id "Connector_Generic:Conn_01x20")
  (at X Y 0)
  (property "Reference" "J1")
  (property "Value" "Pico_Header_Left")
)
(symbol
  (lib_id "Connector_Generic:Conn_01x20")
  (at X Y 0)
  (property "Reference" "J2")
  (property "Value" "Pico_Header_Right")
)
```

---

## 8. 配線完成度

### 8.1 KiCad回路図の構造

KiCad S-expression形式の回路図は以下のセクションで構成される:
1. `lib_symbols`: シンボル定義（ライブラリから参照）
2. `symbol`: シンボルインスタンス（実際のコンポーネント配置）
3. `wire`: ピン間の配線
4. `junction`: 配線の分岐点
5. `no_connect`: 未接続ピンのマーク
6. `label`, `text`: ラベルと注釈

### 8.2 現状の確認

✅ **lib_symbols**: Line 17-471 で定義済み（10種類）
✅ **symbol**: Line 473-1231 で配置済み（31個）
❌ **wire**: **存在しない**
❌ **junction**: **存在しない**
❌ **no_connect**: **存在しない**
✅ **text**: Line 1233-1241 で回路図注釈あり（機能説明）

### 8.3 判定

❌ **配線完成度 0%**: シンボル配置のみ、電気的接続なし

**現状**: 「シンボル配置フェーズ」で止まっている
**次ステップ**: KiCad Eeschema で以下を実行
1. ワイヤツール (W) で各ピンを接続
2. ERC (Electrical Rules Check) 実行
3. ネットリスト生成確認

---

## 総合判定と推奨対応

### 判定: ⚠️ 配線未完成（実装不可）

**現状:**
- 回路図は「コンポーネント配置済み、配線未実施」の状態
- 設計書（ACTUATOR_DESIGN.md）とコンセプトレベルでは整合
- BOM不整合（RefDes, 抵抗値, 欠落部品）あり

**影響:**
- KiCad上でネットリスト生成不可 → PCBレイアウト不可
- ERCエラー多数（未接続ピン警告）

### 推奨対応リスト

#### 優先度A（即座対応）

1. **配線作業**: KiCad Eeschema で全コンポーネントのピン間を配線
   - GP10-13 → R13-16 → U2-5 pin1
   - 3V3/VSYS/GND の電源配線
   - U2-5 pin4 → R1-4 → Q1-4 Gate
   - Q1-4 Drain → K1-4 Coil- (リレー追加後)
   - VSYS → K1-4 Coil+

2. **リレー追加**: K1-K4 のシンボルインスタンス追加
   ```
   (symbol (lib_id "Relay:G5LE-1-DC5") (at X Y 0)
     (property "Reference" "K1")
     (property "Value" "HK19F-DC5V-SHG")
   )
   ```

3. **ピンヘッダ追加**: J1, J2 のシンボルインスタンス追加（Pico接続用）

#### 優先度B（BOM整合性）

4. **設計書BOM修正**:
   - R13-R16 (330Ω, フォトカプラ入力) を追加
   - R1-R4 の値を 330Ω → 100Ω に訂正
   - RefDes統一ルール決定（Pico = U0 or U1）

5. **回路図注釈更新**: Line 1233の text に R13-R16 の説明追加

#### 優先度C（検証）

6. **ERC実行**: KiCad Eeschema で Electrical Rules Check
7. **ネットリスト生成**: Tools → Generate Netlist → Verify
8. **PCBレイアウト試行**: File → New → PCB from Schematic

---

## 設計書（ACTUATOR_DESIGN.md）の評価

### 評価: ✅ 優秀（設計意図が明確）

**良い点:**
- §1-12 の構成が体系的
- 部品選定理由が詳細（§4.1-4.4）
- 電力計算が具体的（§6）
- 安全設計の説明が充実（§7）
- BOMが詳細（JLCPCB品番まで記載）

**改善点:**
- BOMに R13-R16 が欠落
- R1-R4 の値と用途に混乱（330Ω vs 100Ω）
- RefDes が回路図と不一致（U1-U4 vs U2-U5）

**推奨:**
- 回路図完成後に設計書を再レビュー
- BOM表を回路図のネットリストから自動生成

---

## 次ステップ

1. ✅ **本レビュー完了** → 家老に報告
2. ⏳ **配線作業** → 足軽1号または足軽2号に割当
3. ⏳ **BOM修正** → 足軽2号（設計書担当）に依頼
4. ⏳ **ERC検証** → 配線完成後に実施
5. ⏳ **PCBレイアウト** → 回路図完成後の次フェーズ

---

**検証完了**: 2026-02-08
**報告先**: 老中（multiagent:agents.0）
**subtask_288**: completed

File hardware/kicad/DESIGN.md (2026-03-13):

# Grove Shield for Pi Pico 代替基板 設計ドキュメント

**バージョン**: 1.0
**作成日**: 2026-02-07
**ターゲット**: W5500-EVB-Pico-PoE スタック接続

---

## 1. 概要

本基板は、M5Stack Groveエコシステムと互換性のあるI2Cセンサーを、WIZnet W5500-EVB-Pico-PoE基板に接続するためのブレークアウト基板である。

### 主な特徴
- **Grove互換**: M5Stack Grove I2Cセンサー（SHT40, SCD41, BH1750等）を直接接続可能
- **PoE給電対応**: W5500-EVB-Pico-PoEからの3.3V電源供給
- **ADC入力**: アナログセンサー（土壌水分、日射量等）対応
- **スタック接続**: 2×20ピンヘッダで上下にスタック可能

### 使用想定
- 農業IoTノード（温室環境モニタリング）
- W5500-EVB-Pico-PoE基板の上にスタック
- PoE給電でケーブル1本で動作
- MQTTでクラウドにデータ送信

---

## 2. ピンアサイン表

### 完全ピン配置（40ピン）

| GPIO | 機能 | 本基板用途 | 接続先 | 備考 |
|---|---|---|---|---|
| GP0 | UART0 TX | Reserved | - | UART拡張用に予約 |
| GP1 | UART0 RX | Reserved | - | UART拡張用に予約 |
| GP2 | 1-Wire | **1-Wire DS18B20 (J8)** | 土壌温度センサー | 4.7kΩプルアップ(R5) |
| GP3 | GPIO | Reserved | - | 汎用GPIO予約 |
| GP4 | I2C0 SDA | **Grove I2C (J3)** | SHT40, SCD41等 | 4.7kΩプルアップ(R1,R2) |
| GP5 | I2C0 SCL | **Grove I2C (J3)** | 同上 | 4.7kΩプルアップ(R1,R2) |
| GP6 | I2C1 SDA | **Grove I2C (J4)** | BH1750等 | 4.7kΩプルアップ(R3,R4) |
| GP7 | I2C1 SCL | **Grove I2C (J4)** | 同上 | 4.7kΩプルアップ(R3,R4) |
| GP8 | UART1 TX | Reserved | - | UART拡張用に予約 |
| GP9 | UART1 RX | Reserved | - | UART拡張用に予約 |
| GP10 | GPIO | Reserved | - | 汎用GPIO予約 |
| GP11 | GPIO | Reserved | - | 汎用GPIO予約 |
| GP12 | GPIO | Reserved | - | 汎用GPIO予約 |
| GP13 | GPIO | Reserved | - | 汎用GPIO予約 |
| GP14 | GPIO | Reserved | - | 汎用GPIO予約 |
| GP15 | GPIO | Reserved | - | 汎用GPIO予約 |
| **GP16** | **SPI0 MISO** | **W5500_SPI_RESERVED** | W5500 専用 | **使用禁止** |
| **GP17** | **SPI0 CS** | **W5500_SPI_RESERVED** | W5500 専用 | **使用禁止** |
| **GP18** | **SPI0 SCK** | **W5500_SPI_RESERVED** | W5500 専用 | **使用禁止** |
| **GP19** | **SPI0 MOSI** | **W5500_SPI_RESERVED** | W5500 専用 | **使用禁止** |
| **GP20** | **GPIO** | **W5500_SPI_RESERVED** | W5500 RST | **使用禁止** |
| **GP21** | **GPIO** | **W5500_SPI_RESERVED** | W5500 INT | **使用禁止** |
| GP22 | PWM | **Fan PWM (J9)** | 30mm 5V Fan | 25kHz PWM推奨 |
| GP23 | GPIO | Reserved | - | 汎用GPIO予約 |
| GP24 | GPIO | Reserved | - | 汎用GPIO予約 |
| GP25 | GPIO | Reserved | - | 汎用GPIO予約（LED共用注意） |
| GP26 | ADC0 | **ADC Input (J5)** | 土壌水分センサー等 | 3ピンターミナル(GND/3.3V/ADC) |
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

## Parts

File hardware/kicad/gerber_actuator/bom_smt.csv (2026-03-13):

Comment | Designator | Footprint | LCSC
100n | C2 | C_0805_2012Metric | C49678
Red | LED1,LED2,LED3,LED4 | LED_0805_2012Metric | C84256
2N7002 | Q1,Q2,Q3,Q4 | SOT-23 | C8545
330 | R9,R10,R11,R12,R13,R14,R15,R16 | R_0805_2012Metric | C17630
100 | R1,R2,R3,R4 | R_0805_2012Metric | C17408
10k | R5,R6,R7,R8 | R_0805_2012Metric | C17414

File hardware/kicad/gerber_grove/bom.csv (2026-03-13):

Comment | Designator | Footprint | LCSC
100n | C1,C2,C3 | C_0805_2012Metric | C49678
1N4148 | D1 | D_SOD-123 | C81598
Pico_Left | J1 | PinSocket_1x20_P2.54mm_Vertical
Pico_Right | J2 | PinSocket_1x20_P2.54mm_Vertical
Grove_I2C0 | J3 | JST_PH_B4B-PH-K_1x04_P2.00mm_Vertical
Grove_I2C1 | J4 | JST_PH_B4B-PH-K_1x04_P2.00mm_Vertical
ADC0 | J5 | JST_PH_B3B-PH-K_1x03_P2.00mm_Vertical
ADC1 | J6 | JST_PH_B3B-PH-K_1x03_P2.00mm_Vertical
ADC2 | J7 | JST_PH_B3B-PH-K_1x03_P2.00mm_Vertical
1-Wire | J8 | JST_PH_B3B-PH-K_1x03_P2.00mm_Vertical
Fan | J9 | TerminalBlock_bornier-2_P5.08mm
2N7002 | Q1 | SOT-23 | C8545
4.7k | R1,R2,R3,R4,R5 | R_0805_2012Metric | C17673
100 | R6 | R_0805_2012Metric | C17408
10k | R7 | R_0805_2012Metric | C17414

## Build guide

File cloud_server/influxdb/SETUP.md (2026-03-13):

# InfluxDB 2.x セットアップガイド

> **農業施設向けクラウド基盤 - InfluxDB 2.x OSS インストール・設定手順書**
>
> 対象OS: Ubuntu 22.04 / 24.04 LTS
> ターゲットホスト: 192.168.15.14 (Ubuntu PC)
> 更新日: 2026-02-07

## 概要

InfluxDB 2.xは時系列データベースで、農業施設のセンサーデータを長期保存・可視化するために使用します。

**システム構成:**
- Organization: `agri-ha`
- Bucket: `sensor_data` (保存期間: 365日)
- Measurement: `greenhouse_data`
- Tags: `source`, `sensor_type`, `house_id`, `location`
- Fields: `value` (float)
- ポート: 8086 (HTTP API)

## 前提条件

- Ubuntu 22.04 または 24.04 LTS
- root権限（sudo）
- インターネット接続

## インストール手順

### 1. InfluxDB公式リポジトリの追加

```bash
# GPGキーをダウンロード・追加
wget -q https://repos.influxdata.com/influxdata-archive_compat.key
echo '393e8779c89ac8d958f81f942f9ad7fb82a25e133faddaf92e15b16e6ac9ce4c influxdata-archive_compat.key' | sha256sum -c && cat influxdata-archive_compat.key | gpg --dearmor | sudo tee /etc/apt/trusted.gpg.d/influxdata-archive_compat.gpg > /dev/null

# リポジトリを追加
echo 'deb [signed-by=/etc/apt/trusted.gpg.d/influxdata-archive_compat.gpg] https://repos.influxdata.com/debian stable main' | sudo tee /etc/apt/sources.list.d/influxdata.list
```

### 2. InfluxDBのインストール

```bash
# パッケージリストを更新
sudo apt-get update

# InfluxDB 2.x をインストール
sudo apt-get install -y influxdb2 influxdb2-cli
```

### 3. InfluxDBサービスの起動

```bash
# サービスを有効化・起動
sudo systemctl enable influxdb
sudo systemctl start influxdb

# ステータス確認
sudo systemctl status influxdb
```

**期待される出力:**
```
● influxdb.service - InfluxDB is an open-source, distributed, time series database
     Loaded: loaded (/lib/systemd/system/influxdb.service; enabled; vendor preset: enabled)
     Active: active (running) since ...
```

### 4. 初期セットアップ

ブラウザまたはCLIで初期設定を行います。

#### 4.1 CLI経由のセットアップ（推奨）

```bash
influx setup
```

**対話的プロンプトで以下を入力:**

| 項目 | 入力値 |
|---|---|
| Username | `admin` |
| Password | `<強固なパスワード>` (12文字以上、英数字記号混在) |
| Confirm Password | (同じパスワード) |
| Primary Organization Name | `agri-ha` |
| Primary Bucket Name | `sensor_data` |
| Retention Period | `365d` |

**セットアップ完了後、以下が表示されます:**

```
User            Organization    Bucket
admin           agri-ha         sensor_data
```

**重要:** 表示されるAPIトークンを必ず安全に保存してください。

#### 4.2 ブラウザ経由のセットアップ

ブラウザで `http://192.168.15.14:8086` にアクセスし、上記と同じ値を入力します。

### 5. APIトークンの生成（Telegraf用）

Telegrafからデータを書き込むためのAPIトークンを作成します。

```bash
# Telegraf用の読み書き権限トークンを生成
influx auth create \
  --org agri-ha \
  --read-buckets \
  --write-buckets \
  --description "Telegraf MQTT to InfluxDB token"
```

**出力例:**
```
ID                      Description                             Token                           User Name       User ID                 Permissions
0abc123def456           Telegraf MQTT to InfluxDB token         xyz789...                       admin           0abc123def456           [read:orgs/... write:orgs/...]
```

生成されたトークンをTelegraf設定ファイル（`telegraf.conf`）に記載します。

### 6. データ確認コマンド

#### 6.1 Fluxクエリで最新10件取得

```bash
influx query 'from(bucket: "sensor_data")
  |> range(start: -1h)
  |> filter(fn: (r) => r._measurement == "greenhouse_data")
  |> limit(n: 10)'
```

#### 6.2 特定センサータイプのデータ取得（温度）

```bash
influx query 'from(bucket: "sensor_data")
  |> range(start: -24h)
  |> filter(fn: (r) => r._measurement == "greenhouse_data")
  |> filter(fn: (r) => r.sensor_type == "temperature")
  |> limit(n: 100)'
```

#### 6.3 Webインターフェースでデータ確認

ブラウザで `http://192.168.15.14:8086` にアクセスし、左メニューの「Data Explorer」から視覚的にデータを確認できます。

### 7. ファイアウォール設定

外部ホスト（Picoノード等）からInfluxDBにアクセスする場合、ポート8086を開放します。

#### UFWの場合（Ubuntu標準）

```bash
# ポート8086を開放
sudo ufw allow 8086/tcp

# ルール確認
sudo ufw status
```

#### iptablesの場合

```bash
# ポート8086を開放
sudo iptables -A INPUT -p tcp --dport 8086 -j ACCEPT

# 設定を永続化
sudo netfilter-persistent save
```

**セキュリティ注意:**
- 本番環境では、特定IPアドレスのみ許可することを推奨します。
- 例: `sudo ufw allow from 192.168.15.0/24 to any port 8086`

### 8. systemdサービス管理

```bash
# サービス起動
sudo systemctl start influxdb

# サービス停止
sudo systemctl stop influxdb

# サービス再起動
sudo systemctl restart influxdb

# ステータス確認
sudo systemctl status influxdb

# 自動起動設定
sudo systemctl enable influxdb

# 自動起動解除
sudo systemctl disable influxdb
```

### 9. ログ確認

```bash
# InfluxDBログをリアルタイム表示
sudo journalctl -u influxdb -f

# 最新100行を表示
sudo journalctl -u influxdb -n 100
```

## データスキーマ

農業施設向けシステムで使用するInfluxDBデータスキーマ:

### Measurement: `greenhouse_data`

| フィールド/タグ | 種類 | 説明 | 例 |
|---|---|---|-----|
| `source` | Tag | データソース | `pico_node_01`, `weather_station` |
| `sensor_type` | Tag | センサータイプ | `temperature`, `humidity`, `co2` |
| `house_id` | Tag | ハウスID | `house_01` |
| `location` | Tag | 設置場所 | `indoor`, `outdoor` |
| `value` | Field (float) | センサー値 | `25.0`, `75.0` |

### MQTTトピック構造

```
greenhouse/{house_id}/sensor/{sensor_type}
```

**例:**
- `greenhouse/h1/sensor/temperature` → 気温
- `greenhouse/h1/sensor/humidity` → 湿度
- `greenhouse/h1/sensor/co2` → CO2濃度

TelegrafのMQTT Consumerプラグインがこのトピックを購読し、InfluxDBに書き込みます。

## トラブルシューティング

### 1. サービスが起動しない

```bash
# ログを確認
sudo journalctl -u influxdb -n 100 --no-pager

# ポート8086が他のプロセスに使われていないか確認
sudo lsof -i :8086
```

### 2. `influx` コマンドが見つからない

```bash
# influxdb2-cliがインストールされているか確認
dpkg -l | grep influxdb2-cli

# 未インストールの場合
sudo apt-get install -y influxdb2-cli
```

### 3. APIトークンを忘れた

```bash
# 既存のトークン一覧を表示
influx auth list
```

新しいトークンを作成する場合は「5. APIトークンの生成」を参照。

### 4. データが書き込まれない

```bash
# Bucketが存在するか確認
influx bucket list

# 権限を確認
influx auth list
```

Telegraf側のログも確認:
```bash
sudo journalctl -u telegraf -f
```

## セキュリティベストプラクティス

1. **APIトークンの管理**
   - トークンをGitにコミットしない
   - 環境変数または別ファイル（`.env`等）で管理
   - 最小権限の原則（必要な権限のみ付与）

2. **ファイアウォール設定**
   - 必要最小限のIPアドレスのみ許可
   - VPN経由でのアクセスを推奨

3. **定期バックアップ**
   - InfluxDBデータディレクトリ: `/var/lib/influxdb2/`
   - 設定ファイル: `/etc/influxdb/`

4. **アップデート**
   ```bash
   sudo apt-get update
   sudo apt-get upgrade influxdb2 influxdb2-cli
   ```

## 参考リンク

- [InfluxDB 2.x 公式ドキュメント](https://docs.influxdata.com/influxdb/v2/)
- [Flux クエリ言語リファレンス](https://docs.influxdata.com/flux/v0/)
- [Telegraf MQTT Consumer Plugin](https://github.com/influxdata/telegraf/tree/master/plugins/inputs/mqtt_consumer)

## 次のステップ

1. Telegrafのインストール・設定（`../telegraf/SETUP.md` 参照）
2. Grafanaのインストール・設定（`../grafana/SETUP.md` 参照）
3. Grafanaダッシュボードの構築

---

**作成者:** agri-ha DevOps Team
**更新日:** 2026-02-07
**バージョン:** 1.0

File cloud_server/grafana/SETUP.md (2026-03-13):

# Grafana セットアップ手順

> Agricultural Facility 自前クラウド基盤 - Grafana OSS インストール・設定手順書
> Target: Ubuntu 22.04/24.04 LTS
> Host: 192.168.15.14
> Updated: 2026-02-07

## 概要

Grafana OSS をインストールし、InfluxDB をデータソースとして設定する。
プロビジョニング機能を使用してデータソースとダッシュボードを自動登録する。

## システム要件

- Ubuntu 22.04 LTS または 24.04 LTS
- InfluxDB 2.x がインストール済み（http://localhost:8086）
- 最小メモリ: 256MB（推奨: 512MB以上）

## 1. Grafana OSS インストール

### 1.1 公式リポジトリを追加

```bash
# GPGキーを追加
sudo mkdir -p /etc/apt/keyrings/
wget -q -O - https://apt.grafana.com/gpg.key | gpg --dearmor | sudo tee /etc/apt/keyrings/grafana.gpg > /dev/null

# リポジトリを追加
echo "deb [signed-by=/etc/apt/keyrings/grafana.gpg] https://apt.grafana.com stable main" | sudo tee /etc/apt/sources.list.d/grafana.list
```

### 1.2 Grafana をインストール

```bash
sudo apt-get update
sudo apt-get install -y grafana
```

### 1.3 systemd サービスを有効化・起動

```bash
sudo systemctl daemon-reload
sudo systemctl enable grafana-server
sudo systemctl start grafana-server
```

### 1.4 起動確認

```bash
sudo systemctl status grafana-server
```

出力例:
```
● grafana-server.service - Grafana instance
     Loaded: loaded (/lib/systemd/system/grafana-server.service; enabled; vendor preset: enabled)
     Active: active (running) since ...
```

## 2. 初期アクセス

### 2.1 Webブラウザでアクセス

```
http://192.168.15.14:3000
```

### 2.2 初回ログイン

- **ユーザー名**: `admin`
- **パスワード**: `admin`

初回ログイン後、新しいパスワードへの変更を求められる。

## 3. InfluxDB データソース設定

### 3.1 手動設定（GUI）

1. 左サイドバー: Configuration（歯車アイコン） → Data sources
2. "Add data source" をクリック
3. "InfluxDB" を選択
4. 以下のパラメータを設定:

| 項目 | 値 |
|---|-----|
| Name | InfluxDB-Agricultural Facility |
| Query Language | **Flux** |
| URL | `http://localhost:8086` |
| Access | Server (default) |
| Organization | `agri-ha` |
| Default Bucket | `sensor_data` |
| Token | （InfluxDB APIトークン） |

5. "Save & Test" をクリックして接続を確認

### 3.2 自動設定（プロビジョニング）

プロビジョニング設定ファイルを配置することで、データソースを自動登録できる。

#### 3.2.1 プロビジョニングディレクトリ

Grafana のプロビジョニング設定は以下のディレクトリに配置:

```
/etc/grafana/provisioning/
├── datasources/   # データソース定義
└── dashboards/    # ダッシュボード定義
```

#### 3.2.2 InfluxDB データソース YAML

`/etc/grafana/provisioning/datasources/influxdb.yaml` を作成:

```yaml
apiVersion: 1

datasources:
  - name: InfluxDB-Agricultural Facility
    type: influxdb
    access: proxy
    url: http://localhost:8086
    jsonData:
      version: Flux
      organization: agri-ha
      defaultBucket: sensor_data
      tlsSkipVerify: true
    secureJsonData:
      token: <INFLUXDB_TOKEN>
    editable: true
```

**注意**: `<INFLUXDB_TOKEN>` を実際の InfluxDB API トークンに置き換える。

#### 3.2.3 InfluxDB トークンの取得

InfluxDB の Web UI（http://192.168.15.14:8086）から取得:

1. Load Data → API Tokens
2. "Generate API Token" → "Read/Write Token"
3. Organization: `agri-ha`, Buckets: `sensor_data` を選択
4. 生成されたトークンをコピー

または CLI から取得:

```bash
influx auth list --json | jq -r '.[] | select(.description == "agri-ha-token") | .token'
```

#### 3.2.4 プロビジョニングファイルを配置

```bash
sudo cp influxdb.yaml /etc/grafana/provisioning/datasources/
sudo chown root:grafana /etc/grafana/provisioning/datasources/influxdb.yaml
sudo chmod 640 /etc/grafana/provisioning/datasources/influxdb.yaml
```

Grafana を再起動:

```bash
sudo systemctl restart grafana-server
```

## 4. ダッシュボードプロビジョニング

### 4.1 ダッシュボード定義 YAML

`/etc/grafana/provisioning/dashboards/agri-ha.yaml` を作成:

```yaml
apiVersion: 1

providers:
  - name: 'Agricultural Facility'
    orgId: 1
    folder: 'Agricultural Facility'
    type: file
    disableDeletion: false
    updateIntervalSeconds: 10
    allowUiUpdates: true
    options:
      path: /var/lib/grafana/dashboards/agri-ha
```

### 4.2 ダッシュボード JSON ファイル配置

ダッシュボード JSON ファイルは以下のディレクトリに配置:

```bash
sudo mkdir -p /var/lib/grafana/dashboards/agri-ha
```

ダッシュボード JSON は足軽5が `cloud_server/grafana/dashboards/` に作成する。
作成されたファイルを以下のようにコピー:

```bash
sudo cp cloud_server/grafana/dashboards/*.json /var/lib/grafana/dashboards/agri-ha/
sudo chown -R grafana:grafana /var/lib/grafana/dashboards/agri-ha/
```

Grafana を再起動:

```bash
sudo systemctl restart grafana-server
```

## 5. ファイアウォール設定

### 5.1 ufw（Ubuntu Firewall）を使用している場合

```bash
sudo ufw allow 3000/tcp
sudo ufw reload
```

### 5.2 iptables を使用している場合

```bash
sudo iptables -A INPUT -p tcp --dport 3000 -j ACCEPT
sudo netfilter-persistent save
```

## 6. 動作確認

### 6.1 Grafana アクセス確認

```bash
curl -I http://192.168.15.14:3000/login
```

出力例:
```
HTTP/1.1 200 OK
...
```

### 6.2 データソース確認

Grafana Web UI にログイン後、以下を確認:

1. Configuration → Data sources
2. "InfluxDB-Agricultural Facility" が表示されることを確認
3. データソース詳細画面で "Save & Test" → "Data source is working" が表示されることを確認

### 6.3 ダッシュボード確認

1. Dashboards → Browse
2. "Agricultural Facility" フォルダにダッシュボードが表示されることを確認

## 7. トラブルシューティング

### 7.1 Grafana が起動しない

```bash
# ログを確認
sudo journalctl -u grafana-server -n 100 --no-pager

# 設定ファイルの構文確認
sudo grafana-cli admin reset-admin-password temp123
```

### 7.2 データソース接続エラー

```bash
# InfluxDB が起動しているか確認
sudo systemctl status influxdb

# ポート確認
ss -tlnp | grep 8086

# トークンの有効性確認
influx auth list
```

### 7.3 プロビジョニングが反映されない

```bash
# プロビジョニング設定ファイルのパーミッション確認
ls -la /etc/grafana/provisioning/datasources/
ls -la /etc/grafana/provisioning/dashboards/

# Grafana ログで "provisioning" を検索
sudo journalctl -u grafana-server | grep provisioning
```

## 8. 設定ファイル

### 8.1 Grafana メイン設定

- パス: `/etc/grafana/grafana.ini`
- デフォルト値はコメントアウトされている

主要な設定項目:

```ini
[server]
http_port = 3000

[security]
admin_user = admin
admin_password = admin

[paths]
data = /var/lib/grafana
logs = /var/log/grafana
plugins = /var/lib/grafana/plugins
provisioning = /etc/grafana/provisioning
```

## 9. 参考リンク

- [Grafana公式ドキュメント](https://grafana.com/docs/grafana/latest/)
- [Grafana Provisioning](https://grafana.com/docs/grafana/latest/administration/provisioning/)
- [InfluxDB データソース設定](https://grafana.com/docs/grafana/latest/datasources/influxdb/)
- [Flux クエリ言語](https://docs.influxdata.com/flux/v0.x/)

## 付録: 共通規約

| 項目 | 値 |
|---|-----|
| Organization | agri-ha |
| Bucket | sensor_data |
| InfluxDB URL | http://localhost:8086 |
| Grafana ポート | 3000 |
| ターゲットホスト | 192.168.15.14 |

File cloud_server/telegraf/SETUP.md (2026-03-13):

# Telegraf セットアップ手順書

> **Agricultural Facility  データブリッジ（MQTT → InfluxDB）**
>
> Telegraf を使用して、Mosquitto（MQTT）から InfluxDB v2 へデータを転送します。

---

## 目次

1. [前提条件](#前提条件)
2. [Telegraf インストール](#telegraf-インストール)
3. [設定ファイル配置](#設定ファイル配置)
4. [InfluxDB トークン設定](#influxdb-トークン設定)
5. [起動と確認](#起動と確認)
6. [動作テスト](#動作テスト)
7. [トラブルシューティング](#トラブルシューティング)

---

## 前提条件

以下のサービスが稼働している必要があります：

- **Mosquitto (MQTT Broker)**: localhost:1883
- **InfluxDB v2**: localhost:8086
  - Organization: `agri-ha`
  - Bucket: `sensor_data`

確認コマンド：
```bash
# Mosquitto 確認
systemctl status mosquitto

# InfluxDB 確認
systemctl status influxdb

# MQTT ポート確認
ss -tlnp | grep 1883

# InfluxDB ポート確認
ss -tlnp | grep 8086
```

---

## Telegraf インストール

### 1. InfluxData 公式リポジトリ追加

```bash
# GPG キーをダウンロード
wget -q https://repos.influxdata.com/influxdata-archive_compat.key
echo '393e8779c89ac8d958f81f942f9ad7fb82a25e133faddaf92e15b16e6ac9ce4c influxdata-archive_compat.key' | sha256sum -c && cat influxdata-archive_compat.key | gpg --dearmor | sudo tee /etc/apt/trusted.gpg.d/influxdata-archive_compat.gpg > /dev/null

# リポジトリ追加
echo 'deb [signed-by=/etc/apt/trusted.gpg.d/influxdata-archive_compat.gpg] https://repos.influxdata.com/debian stable main' | sudo tee /etc/apt/sources.list.d/influxdata.list
```

### 2. Telegraf インストール

```bash
sudo apt update
sudo apt install -y telegraf
```

### 3. インストール確認

```bash
telegraf --version
# 出力例: Telegraf 1.28.x
```

---

## 設定ファイル配置

### 1. 設定ファイルをコピー

```bash
sudo cp telegraf_agri-ha.conf /etc/telegraf/telegraf.d/agri-ha.conf
sudo chown root:root /etc/telegraf/telegraf.d/agri-ha.conf
sudo chmod 640 /etc/telegraf/telegraf.d/agri-ha.conf
```

### 2. 設定ファイル確認

```bash
ls -l /etc/telegraf/telegraf.d/agri-ha.conf
```

### 3. デフォルト設定の無効化（オプション）

Telegraf はデフォルトで `/etc/telegraf/telegraf.conf` も読み込みます。
Agricultural Facility 専用設定のみを使用する場合は、デフォルト設定を無効化できます。

```bash
# デフォルト設定をリネーム（バックアップ）
sudo mv /etc/telegraf/telegraf.conf /etc/telegraf/telegraf.conf.bak
```

---

## InfluxDB トークン設定

### 1. InfluxDB トークン取得

InfluxDB UI（http://localhost:8086）にログインし、以下の手順でトークンを取得：

1. 左メニュー「API Tokens」をクリック
2. 既存トークンを選択、または「Generate API Token」→「All Access Token」
3. トークン文字列をコピー

### 2. 環境変数として設定（推奨）

Telegraf 用の環境変数ファイルを作成：

```bash
sudo mkdir -p /etc/telegraf/env
echo 'INFLUX_TOKEN="YOUR_INFLUXDB_TOKEN_HERE"' | sudo tee /etc/telegraf/env/influx.env
sudo chmod 600 /etc/telegraf/env/influx.env
```

**重要**: `YOUR_INFLUXDB_TOKEN_HERE` を実際のトークンに置き換えてください。

### 3. systemd 環境変数読み込み設定

```bash
sudo mkdir -p /etc/systemd/system/telegraf.service.d
cat <<EOF | sudo tee /etc/systemd/system/telegraf.service.d/influx-env.conf
[Service]
EnvironmentFile=/etc/telegraf/env/influx.env
EOF

sudo systemctl daemon-reload
```

### 4. 設定ファイル検証（ドライラン）

```bash
# 環境変数を読み込んでテスト
source /etc/telegraf/env/influx.env
telegraf --config /etc/telegraf/telegraf.d/agri-ha.conf --test

# エラーがなければOK（数秒でCtrl+C）
```

---

## 起動と確認

### 1. Telegraf サービス起動

```bash
sudo systemctl enable telegraf
sudo systemctl start telegraf
```

### 2. 起動確認

```bash
sudo systemctl status telegraf
```

**正常な出力例**:
```
● telegraf.service - The plugin-driven server agent for reporting metrics into InfluxDB
   Loaded: loaded (/lib/systemd/system/telegraf.service; enabled)
   Active: active (running) since ...
```

### 3. ログ確認

```bash
# リアルタイムログ監視
sudo journalctl -u telegraf -f

# エラーのみ表示
sudo journalctl -u telegraf -p err
```

---

## 動作テスト

### 1. テストデータ送信（MQTT）

Mosquitto クライアントでテストデータを送信：

```bash
mosquitto_pub -h localhost -t "agri-ha/greenhouse/WAirTemp" -m '{
  "value": -9.2,
  "sensor_type": "WAirTemp",
  "source": "192.168.1.71",
  "room": "1",
  "region": "1",
  "order": "1",
  "unit": "℃",
  "timestamp": "2026-02-07T12:00:00Z"
}'
```

### 2. InfluxDB でデータ確認

#### 方法1: InfluxDB CLI

```bash
influx query 'from(bucket:"sensor_data") |> range(start: -1h) |> filter(fn: (r) => r._measurement == "greenhouse_data")' \
  --org agri-ha
```

#### 方法2: InfluxDB UI

1. http://localhost:8086 にアクセス
2. 左メニュー「Data Explorer」
3. Bucket: `sensor_data` を選択
4. Measurement: `greenhouse_data` を選択
5. 「Submit」をクリック

データが表示されれば成功です。

### 3. 複数データ種別のテスト

```bash
# 湿度データ
mosquitto_pub -h localhost -t "agri-ha/greenhouse/WAirHumid" -m '{
  "value": 75,
  "sensor_type": "WAirHumid",
  "source": "192.168.1.71",
  "room": "1",
  "region": "1",
  "order": "1",
  "unit": "%",
  "timestamp": "2026-02-07T12:01:00Z"
}'

# 風速データ
mosquitto_pub -h localhost -t "agri-ha/greenhouse/WWindSpeed" -m '{
  "value": 2.5,
  "sensor_type": "WWindSpeed",
  "source": "192.168.1.71",
  "room": "1",
  "region": "1",
  "order": "1",
  "unit": "m/s",
  "timestamp": "2026-02-07T12:02:00Z"
}'
```

---

## トラブルシューティング

### 問題: データが InfluxDB に書き込まれない

#### 1. Telegraf 設定テスト

```bash
source /etc/telegraf/env/influx.env
telegraf --config /etc/telegraf/telegraf.d/agri-ha.conf --test --input-filter mqtt_consumer
```

正常なら `greenhouse_data` というメトリクスが表示されます。

#### 2. MQTT 接続確認

```bash
# MQTT サブスクライブテスト
mosquitto_sub -h localhost -t "agri-ha/greenhouse/#" -v
```

別ターミナルで `mosquitto_pub` でデータ送信し、受信できるか確認。

#### 3. InfluxDB トークン確認

```bash
# 環境変数確認
sudo systemctl show telegraf | grep INFLUX_TOKEN

# トークンが表示されない場合、環境変数が読み込まれていない
```

#### 4. InfluxDB 接続テスト

```bash
curl -H "Authorization: Token YOUR_TOKEN" \
  http://localhost:8086/api/v2/buckets?org=agri-ha
```

正常なら bucket 情報が JSON で返ります。

### 問題: Telegraf が起動しない

#### ログ確認

```bash
sudo journalctl -u telegraf -n 50 --no-pager
```

**よくあるエラー**:

1. **設定ファイル構文エラー**
   ```bash
   telegraf --config /etc/telegraf/telegraf.d/agri-ha.conf --test
   ```

2. **MQTT 接続エラー**
   - Mosquitto が起動しているか確認: `systemctl status mosquitto`
   - ファイアウォール確認: `sudo ufw status`

3. **InfluxDB 接続エラー**
   - InfluxDB が起動しているか確認: `systemctl status influxdb`
   - トークンが正しいか確認

### 問題: データが重複して書き込まれる

複数の Telegraf プロセスが起動している可能性があります。

```bash
ps aux | grep telegraf
sudo systemctl restart telegraf
```

### デバッグ用ログ出力

一時的にファイル出力を有効化して、Telegraf が受信しているデータを確認：

```bash
# /etc/telegraf/telegraf.d/agri-ha.conf の末尾に追加
sudo tee -a /etc/telegraf/telegraf.d/agri-ha.conf <<EOF

[[outputs.file]]
  files = ["/tmp/telegraf_debug.log"]
  data_format = "influx"
EOF

sudo systemctl restart telegraf

# ログ確認
tail -f /tmp/telegraf_debug.log
```

テスト後は outputs.file セクションをコメントアウトしてください。

---

## 設定ファイル構造

```
/etc/telegraf/
├── telegraf.conf.bak          # デフォルト設定（無効化済み）
├── telegraf.d/
│   └── agri-ha.conf          # Agricultural Facility 専用設定
└── env/
    └── influx.env             # InfluxDB トークン（環境変数）
```

---

## 次のステップ

1. **Grafana ダッシュボード作成**
   - InfluxDB をデータソースとして追加
   - greenhouse_data メトリクスを可視化

2. **- ブリッジスクリプト設定**
   - Agricultural Facility から UDP マルチキャスト受信
   - MQTT へ変換・送信

3. **アラート設定**
   - Grafana でしきい値アラート設定
   - LINE Messaging API 連携

---

## 参考資料

- [Telegraf 公式ドキュメント](https://docs.influxdata.com/telegraf/)
- [MQTT Consumer Plugin](https://github.com/influxdata/telegraf/tree/master/plugins/inputs/mqtt_consumer)
- [InfluxDB v2 Output Plugin](https://github.com/influxdata/telegraf/tree/master/plugins/outputs/influxdb_v2)
- [Agricultural Facility  仕様](../../context/agri-ha.md)

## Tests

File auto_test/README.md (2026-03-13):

# Pico 2 W 無人自動テスト環境

Pico 2 WをUSB接続すると自動でテストが実行され、結果がLINEに通知される。

## ファイル構成

```
auto_test/
├── auto_test_runner.py    # メインテストスクリプト
├── notify.py              # 通知モジュール
├── test_config.json       # 設定ファイル
├── requirements.txt       # Python依存パッケージ
├── README.md              # このファイル
├── udev/
│   └── 99-pico-test.rules # USB検知ルール
├── systemd/
│   └── pico-test.service  # テストサービス
└── results/               # テスト結果（自動生成）
```

## セットアップ手順

### 1. Python依存パッケージのインストール

```bash
pip3 install -r requirements.txt
```

### 2. ユーザーをdialoutグループに追加

```bash
sudo usermod -a -G dialout $USER
# ログアウト・ログインが必要
```

### 3. ログディレクトリ作成

```bash
sudo mkdir -p /var/log/arsprout
sudo chown $USER:$USER /var/log/arsprout
```

### 4. LINE Notifyトークン設定

1. https://notify-bot.line.me/ja/ にアクセス
2. ログイン -> マイページ -> トークン発行
3. トークン名: "Pico Test" など
4. 通知先: 自分のLINEアカウント
5. `test_config.json` の `notification.token` に設定

```json
{
    "notification": {
        "type": "line",
        "token": "発行されたトークンをここに貼り付け"
    }
}
```

### 5. udevルール配置

```bash
sudo cp udev/99-pico-test.rules /etc/udev/rules.d/
sudo udevadm control --reload-rules
sudo udevadm trigger
```

### 6. systemdサービス配置

```bash
sudo cp systemd/pico-test.service /etc/systemd/system/
sudo systemctl daemon-reload
```

## 使用方法

### 自動実行

Pico 2 W（CircuitPythonインストール済み）をUSB接続すると、
自動的にテストが実行されLINEに結果が通知される。

### 手動実行

```bash
# 通知なし
python3 auto_test_runner.py

# LINE通知あり
python3 auto_test_runner.py --notify

# 設定ファイル指定
python3 auto_test_runner.py --config /path/to/config.json --notify
```

### サービスとして手動起動

```bash
sudo systemctl start pico-test.service
```

## テスト項目

| ID | テスト項目 | 内容 | タイムアウト |
|----|---|---|---|
| USB-001 | デバイス認識 | Picoポートの検出 | 10秒 |
| USB-002 | シリアル接続 | 115200bpsで接続 | 5秒 |
| USB-003 | REPL応答 | Ctrl+Cでプロンプト表示 | 5秒 |
| USB-004 | CPU温度読み取り | microcontroller.cpu.temperature | 5秒 |
| USB-005 | エコーテスト | print()の応答確認 | 5秒 |

## ログ確認

```bash
# テストログ
tail -f /var/log/arsprout/pico_test.log

# udevイベントログ
journalctl -t pico-udev -f

# サービスログ
journalctl -u pico-test.service -f
```

## トラブルシューティング

### デバイスが認識されない

```bash
# 接続されているUSBデバイス確認
lsusb | grep -i pico

# シリアルポート確認
ls -la /dev/ttyACM*

# udevルール確認
udevadm test /sys/class/tty/ttyACM0
```

### 権限エラー

```bash
# dialoutグループ確認
groups $USER

# 手動で権限変更（一時的）
sudo chmod 666 /dev/ttyACM0
```

### CircuitPythonがインストールされていない

Pico 2 W用のCircuitPython UF2をインストール:
1. BOOTSELボタンを押しながらUSB接続
2. RPI-RP2ドライブが表示される
3. UF2ファイルをドラッグ&ドロップ

ダウンロード: https://circuitpython.org/board/raspberry_pi_pico2_w/

## 安全ガイドライン

- テスト中にPicoを抜かないこと
- 異常発生時はCtrl+Cで中断可能
- ログファイルのディスク使用量に注意

## 関連ドキュメント

- [CircuitPython Pico 2 W](https://circuitpython.org/board/raspberry_pi_pico2_w/)
- [LINE Notify API](https://notify-bot.line.me/doc/ja/)
- [udev man page](https://www.freedesktop.org/software/systemd/man/udev.html)

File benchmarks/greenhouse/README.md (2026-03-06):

# 温室制御LLMベンチマーク

長ナス農家専属AIの判断品質を測定するベンチマークスイート。
system_prompt.txtに記載された農家知恵ルール(4ルール)への対応を7シナリオで評価する。

## シナリオ一覧

| ID | カテゴリ | シナリオ名 | 対応ルール |
|----|---|---|---|
| S01 | 殿指定 | 外部湿度100%正しい無視 | ルール1 |
| S02 | 殿指定 | 気温急上昇先読み開放 | ルール2 |
| S03 | 殿指定 | 朝の湿度優先開放 | ルール3 |
| S04 | 追加 | CO2低下パルス換気（雨天） | ルール4 |
| S05 | 追加 | 高温緊急全窓全開 | 基本ルール |
| S06 | 追加 | 夜間低温・暖房ON+全窓閉 | 基本ルール |
| S07 | 追加 | 北風強風・方角別制御 | 基本ルール |

## 評価軸

1. **論理整合性** (0-10点/シナリオ): set_relay の呼び出しが期待通りか
2. **JSON構文検証**: LLM応答テキストにJSONが含まれる場合にパース可能か
3. **時間軸リニア性**: 複数ステップのプランがタイムスタンプ順か

合格ライン: 各シナリオ6点以上 (60%)

## 使い方

```bash
# NullClaw (デフォルト、agriha-nullclaw-proxy が起動していること)
cd /home/yasu/uecs-llm
python benchmarks/greenhouse/runner.py

# Claude Haiku
python benchmarks/greenhouse/runner.py \
  --base-url https://api.anthropic.com/v1 \
  --model claude-haiku-4-5-20251001 \
  --api-key $ANTHROPIC_API_KEY

# 特定シナリオのみ + 詳細ログ
python benchmarks/greenhouse/runner.py --scenarios S01,S03 --verbose

# 結果をJSONに保存
python benchmarks/greenhouse/runner.py \
  --output results/nullclaw_$(date +%Y%m%d).json
```

## 依存パッケージ

- `openai` (既にpyproject.tomlに含まれる)

## ファイル構成

```
benchmarks/greenhouse/
  scenarios/
    S01_outside_humidity_ignore.json    # 殿指定: 外部湿度無視
    S02_temp_spike_preemptive.json      # 殿指定: 気温急上昇先読み
    S03_morning_humidity_priority.json  # 殿指定: 朝の湿度優先
    S04_co2_pulse_ventilation.json      # CO2パルス換気（雨天）
    S05_heat_emergency.json             # 高温緊急全窓全開
    S06_night_heating.json              # 夜間低温暖房ON
    S07_wind_direction.json             # 強風方角別制御
  runner.py     # ベンチマーク実行スクリプト (CLI)
  evaluate.py   # 評価ロジック (スコアリング)
  README.md     # このファイル
```

## スコアリング詳細

各シナリオは `grading.criteria` に複数の評価基準を持つ。
set_relay の呼び出し結果（チャンネル・値・duration_sec）と比較し、
最も高い点数の基準に一致したものをスコアとする。

`grading.forbidden_conditions` に該当する場合はペナルティが適用される。

### S04 パルス換気の評価について

CO2パルス換気シナリオ(S04)では `duration_sec > 0` の set_relay を
呼んだ場合に満点(10点)、duration_secなしの場合は7点となる。
これにより「パルス換気の概念を理解しているか」を測定できる。

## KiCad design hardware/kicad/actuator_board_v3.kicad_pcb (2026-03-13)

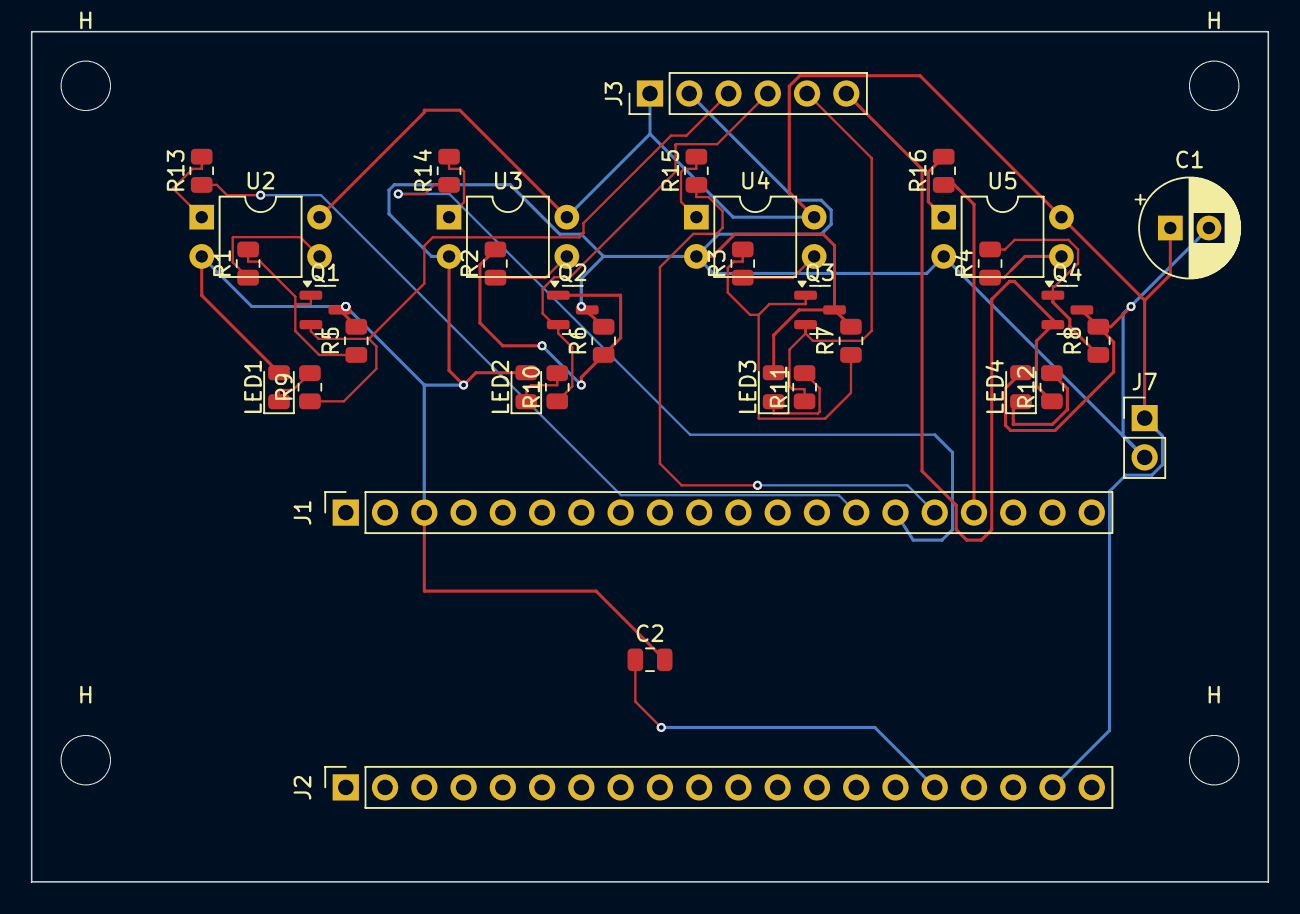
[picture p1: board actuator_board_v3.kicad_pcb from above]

Board: 2 copper layers, 80.0 x 55.0 mm, 38 parts (0 on the bottom side), 27 nets.

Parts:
C1: 100u; CP_Radial_D6.3mm_P2.50mm
C2: 100n; C_0805_2012Metric
H: MountingHole_3.2mm_M3
H#2, H#3, H#4: MountingHole_3.2mm_M3
J1: Pico_Left; PinSocket_1x20_P2.54mm_Vertical
J2: Pico_Right; PinSocket_1x20_P2.54mm_Vertical
J3: RELAY_MOD; PinHeader_1x06_P2.54mm_Vertical
J7: 5V_EXT; PinHeader_1x02_P2.54mm_Vertical
LED1, LED2, LED3, LED4: Red; LED_0805_2012Metric
Q1, Q2, Q3, Q4: 2N7002; SOT-23
R1, R2, R3, R4: 100; R_0805_2012Metric
R5, R6, R7, R8: 10k; R_0805_2012Metric
R9, R10, R11, R12, R13, R14, R15, R16: 330; R_0805_2012Metric
U2, U3, U4, U5: PC817; DIP-4_W7.62mm

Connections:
unnamed: C1.1, J2.19, J3.1, J7.1, U2.4, U3.4, U4.4, U5.4
unnamed: C1.2, C2.2, J1.3, J3.2, J7.2, LED1.2, LED2.2, LED3.2, LED4.2, Q1.3, Q2.3, Q3.3, Q4.3, R5.2, R6.2, R7.2, R8.2, U2.2, U3.2, U4.2, U5.2
unnamed: J1.14, R13.1
unnamed: J1.15, R14.1
unnamed: J1.16, R15.1
unnamed: J1.17, R16.1
unnamed: C2.1, J2.16
unnamed: LED1.1, R9.2
unnamed: LED2.1, R10.2
unnamed: LED3.1, R11.2
unnamed: LED4.1, R12.2
unnamed: J3.3, Q1.2, R9.1
unnamed: Q1.1, R1.2, R5.1
unnamed: J3.4, Q2.2, R10.1
unnamed: Q2.1, R2.2, R6.1
unnamed: J3.5, Q3.2, R11.1
unnamed: Q3.1, R3.2, R7.1
unnamed: J3.6, Q4.2, R12.1
unnamed: Q4.1, R4.2, R8.1
unnamed: R1.1, U2.3
unnamed: R2.1, U3.3
unnamed: R3.1, U4.3
unnamed: R4.1, U5.3
unnamed: R13.2, U2.1
unnamed: R14.2, U3.1
unnamed: R15.2, U4.1
unnamed: R16.2, U5.1

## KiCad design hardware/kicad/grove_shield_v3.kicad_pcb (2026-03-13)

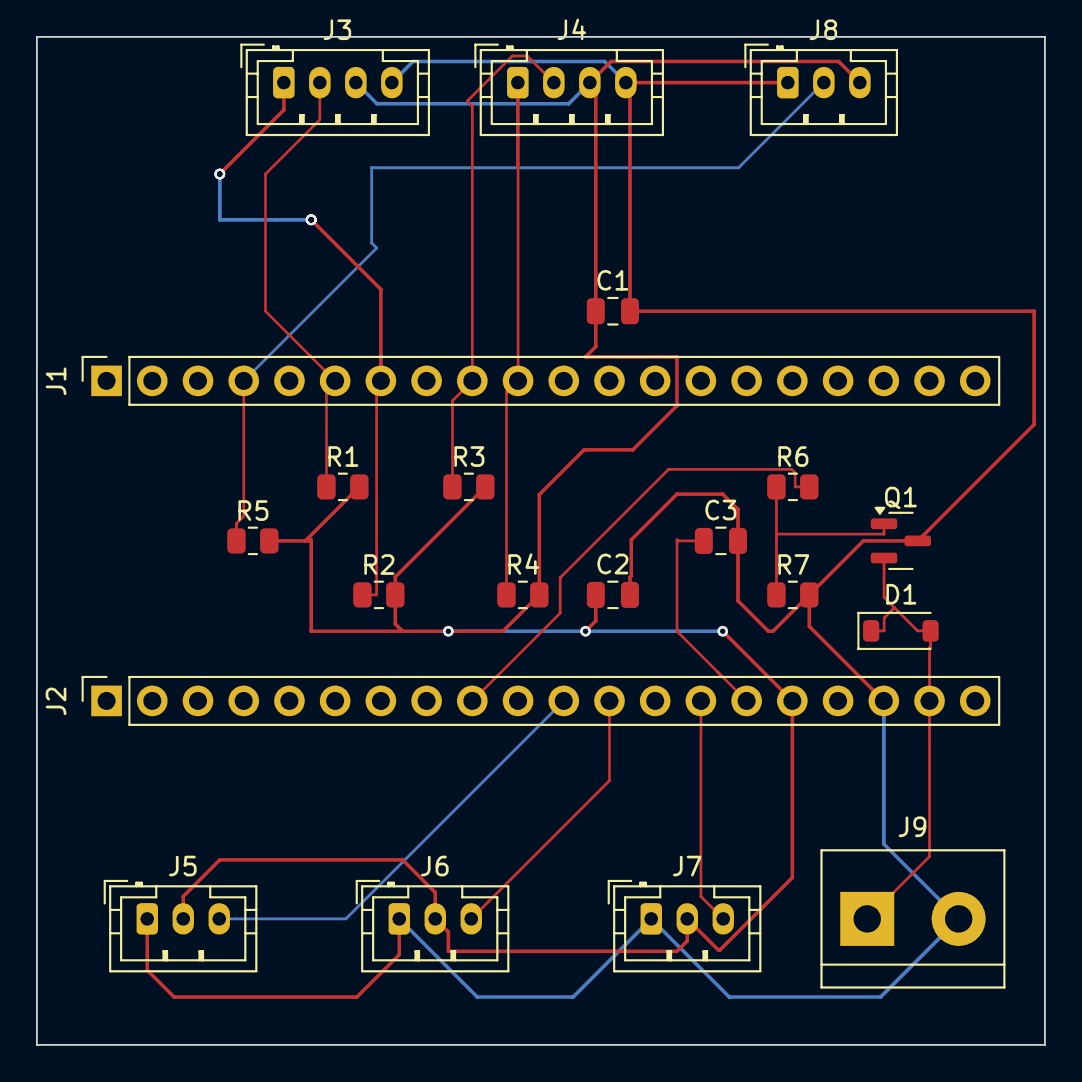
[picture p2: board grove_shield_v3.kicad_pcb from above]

Board: 2 copper layers, 56.0 x 56.0 mm, 21 parts (0 on the bottom side), 14 nets.

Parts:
C1, C2, C3: 100n; C_0805_2012Metric
D1: 1N4148; D_SOD-123
J1: Pico_Left; PinSocket_1x20_P2.54mm_Vertical
J2: Pico_Right; PinSocket_1x20_P2.54mm_Vertical
J3: Grove_I2C0; JST_PH_B4B-PH-K_1x04_P2.00mm_Vertical
J4: Grove_I2C1; JST_PH_B4B-PH-K_1x04_P2.00mm_Vertical
J5: ADC0; JST_PH_B3B-PH-K_1x03_P2.00mm_Vertical
J6: ADC1; JST_PH_B3B-PH-K_1x03_P2.00mm_Vertical
J7: ADC2; JST_PH_B3B-PH-K_1x03_P2.00mm_Vertical
J8: 1-Wire; JST_PH_B3B-PH-K_1x03_P2.00mm_Vertical
J9: Fan; TerminalBlock_bornier-2_P5.08mm
Q1: 2N7002; SOT-23
R1, R2, R3, R4, R5: 4.7k; R_0805_2012Metric
R6: 100; R_0805_2012Metric
R7: 10k; R_0805_2012Metric

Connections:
unnamed: D1.1, D1.2, J2.19, J9.1, Q1.2
unnamed: J1.4, J8.2, R5.1
unnamed: J1.6, J3.2, R1.1
unnamed: J1.7, J3.1, R2.1
unnamed: J1.9, J4.2, R3.1
unnamed: J1.10, J4.1, R4.1
unnamed: J2.9, R6.2
unnamed: J2.11, J5.3
unnamed: J2.12, J6.3
unnamed: J2.14, J7.3
unnamed: C3.1, J2.15
unnamed: C1.1, C2.1, J2.16, J3.3, J4.3, J5.2, J6.2, J7.2, J8.3, R1.2, R2.2, R3.2, R4.2, R5.2
unnamed: C1.2, C2.2, C3.2, J2.18, J3.4, J4.4, J5.1, J6.1, J7.1, J8.1, J9.2, Q1.3, R7.2
unnamed: Q1.1, R6.1, R7.1

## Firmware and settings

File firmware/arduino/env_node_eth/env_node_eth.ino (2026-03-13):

// env_node_eth.ino - Environment Sensor Node for W5500-EVB-Pico2
// I2C auto-detect: SCD41 + SHT40 + BMP280 (only detected sensors are used)
// Ethernet (PoE) + MQTT data transmission + HA Auto Discovery
// arduino-pico v5.5.0, PubSubClient 2.8, ArduinoJson 7.x, Sensirion drivers, Adafruit BMP280

#include <SPI.h>
#include <W5500lwIP.h>
#include <PubSubClient.h>
#include <ArduinoJson.h>
#include <LittleFS.h>
#include <Wire.h>

// Shared headers
#include "sensor_registry.h"
#include "sw_watchdog.h"

// Sensirion official drivers
#include <SensirionI2cScd4x.h>
#include <SensirionI2cSht4x.h>
// Adafruit BMP280
#include <Adafruit_BMP280.h>

// ========== Firmware Version ==========
const char* FW_VERSION = "3.0.1";
const char* FW_NAME = "env_node_eth";

// ========== W5500 SPI0 Pins (W5500-EVB-Pico2 fixed) ==========
const int W5500_CS = 17;
const int W5500_INT = 21;
const int W5500_RST = 20;
// SPI0: MOSI=GP19, MISO=GP16, SCK=GP18

// ========== I2C0 (Grove connector) ==========
const int I2C_SDA = 8;
const int I2C_SCL = 9;

// ========== Compile-time Configuration ==========
const char* DEFAULT_MQTT_BROKER = "192.168.15.14";
const int DEFAULT_MQTT_PORT = 1883;
const char* DEFAULT_HOUSE_ID = "h1";
const char* DEFAULT_NODE_ID = "env_node_eth_01";

// ========== Sensor Calibration ==========
const float SCD41_TEMP_OFFSET = 3.29;
const float BMP280_TEMP_OFFSET = 0.60;

// ========== Timing ==========
const int SENSOR_INTERVAL = 60;  // seconds
const int ETH_CONNECT_TIMEOUT = 15;  // seconds
const int MQTT_RECONNECT_ATTEMPTS = 3;
const int MQTT_RECONNECT_DELAY = 5;  // seconds
const unsigned long REBOOT_INTERVAL = 600000;  // 10 minutes
const int MQTT_FAIL_THRESHOLD = 3;

// ========== Global Variables (Core 0) ==========
Wiznet5500lwIP eth(W5500_CS, SPI, W5500_INT);
WiFiClient wifiClient;
PubSubClient mqttClient(wifiClient);

String houseId;
String nodeId;
String mqttBroker;
int mqttPort;
String mqttClientId;
String mqttTopic;

int mqttFailCount = 0;
int loopCount = 0;

// ========== I2C Sensor Detection Flags ==========
bool scd41_detected = false;
bool sht40_detected = false;
bool bmp280_detected = false;

// ========== Shared Variables (volatile, Core 0 <-> Core 1) ==========
volatile float g_co2 = NAN;
volatile float g_scd41_temp = NAN;
volatile float g_scd41_hum = NAN;
volatile float g_sht40_temp = NAN;
volatile float g_sht40_hum = NAN;
volatile float g_pressure = NAN;
volatile float g_bmp280_temp = NAN;
volatile bool g_data_ready = false;
volatile bool g_sensors_ok = false;

// ========== Sensor Objects (Core 1) ==========
SensirionI2cScd4x scd4x;
SensirionI2cSht4x sht4x;
Adafruit_BMP280 bmp280(&Wire);

// ========== Function Declarations ==========
void loadConfig();
void initEthernet();
void connectMQTT();
void publishHADiscovery();
void rebootWithReason(const char* reason);

// ========== Core 0: Setup (Networking) ==========
void setup() {
  Serial.begin(115200);
  delay(2000);

  Serial.println("=== env_node_eth.ino: Environment Sensor Node (Ethernet) ===");
  Serial.println("Board: W5500-EVB-Pico2");
  Serial.println("Sensors: I2C auto-detect (SCD41/SHT40/BMP280)");

  // LittleFS initialization
  if (!LittleFS.begin()) {
    Serial.println("LittleFS mount failed, formatting...");
    LittleFS.format();
    if (!LittleFS.begin()) {
      Serial.println("WARNING: LittleFS init failed after format");
      Serial.println("Continuing with default configuration (LittleFS disabled)");
    } else {
      Serial.println("LittleFS formatted and mounted");
    }
  } else {
    Serial.println("LittleFS mounted");
  }

  // Load configuration
  loadConfig();

  Serial.printf("Node: %s, House: %s\n", nodeId.c_str(), houseId.c_str());
  Serial.printf("MQTT: %s:%d, Topic: %s\n", mqttBroker.c_str(), mqttPort, mqttTopic.c_str());

  // Ethernet connection
  initEthernet();

  // MQTT connection
  mqttClient.setServer(mqttBroker.c_str(), mqttPort);
  mqttClient.setKeepAlive(60);
  mqttClient.setBufferSize(256);
  connectMQTT();

  // HA MQTT Auto Discovery (deferred until sensors detected)
  // publishHADiscovery() is called after g_sensors_ok is set

  // Publish firmware version (retained)
  String versionTopic = String("agriha/") + nodeId + "/version";
  String versionPayload = String("{\"firmware\":\"") + FW_NAME + "\",\"version\":\"" + FW_VERSION + "\"}";
  mqttClient.publish(versionTopic.c_str(), versionPayload.c_str(), true);
  Serial.printf("Published firmware version: %s v%s\n", FW_NAME, FW_VERSION);

  // Start software watchdog
  swWdtStart();
  Serial.printf("Software watchdog: check %lums, threshold %d misses (%lus)\n",
                SWD_CHECK_MS, SWD_MISS_THRESHOLD, SWD_CHECK_MS * SWD_MISS_THRESHOLD / 1000);

  Serial.println("\n=== Core 0 Setup Complete ===\n");
}

// ========== Core 1: Setup (Sensors - I2C Auto Detect) ==========
void setup1() {
  Serial.println("=== Core 1 Setup: I2C Auto Detect ===");

  Wire.setSDA(I2C_SDA);
  Wire.setSCL(I2C_SCL);
  Wire.begin();
  delay(1000);

  // I2C scan -> registry lookup
  Serial.println("I2C scan:");
  for (uint8_t addr = 1; addr < 127; addr++) {
    Wire.beginTransmission(addr);
    if (Wire.endTransmission() == 0) {
      Serial.printf("  0x%02X found -> ", addr);
      bool matched = false;
      for (int i = 0; i < SENSOR_REGISTRY_SIZE; i++) {
        if (SENSOR_REGISTRY[i].addr == addr) {
          Serial.printf("%s\n", SENSOR_REGISTRY[i].name);
          switch (SENSOR_REGISTRY[i].type) {
            case SENSOR_SCD41:  scd41_detected = true;  break;
            case SENSOR_SHT40:  sht40_detected = true;  break;
            case SENSOR_BMP280: bmp280_detected = true;  break;
            default: break;
          }
          matched = true;
          break;
        }
      }
      if (!matched) Serial.println("unknown");
    }
  }

  Serial.printf("Detected: SCD41=%d SHT40=%d BMP280=%d\n",
                scd41_detected, sht40_detected, bmp280_detected);

  // Initialize only detected sensors
  if (scd41_detected) {
    scd4x.begin(Wire, 0x62);
    uint16_t error;
    char errorMessage[256];

    error = scd4x.stopPeriodicMeasurement();
    if (error) {
      errorToString(error, errorMessage, 256);
      Serial.printf("SCD41 stopPeriodicMeasurement error: %s\n", errorMessage);
    }
    delay(500);

    uint64_t serialNumber;
    error = scd4x.getSerialNumber(serialNumber);
    if (error) {
      errorToString(error, errorMessage, 256);
      Serial.printf("SCD41 getSerialNumber error: %s\n", errorMessage);
    } else {
      Serial.printf("SCD41 serial: 0x%012llX\n", serialNumber);
    }

    error = scd4x.startPeriodicMeasurement();
    if (error) {
      errorToString(error, errorMessage, 256);
      Serial.printf("SCD41 startPeriodicMeasurement error: %s\n", errorMessage);
    } else {
      Serial.println("SCD41 periodic measurement started (5s interval)");
    }
  }

  if (sht40_detected) {
    sht4x.begin(Wire, 0x44);
    Serial.println("SHT40 initialized at 0x44");
  }

  if (bmp280_detected) {
    if (!bmp280.begin(0x76)) {
      if (!bmp280.begin(0x77)) {
        Serial.println("BMP280 init failed (detected but begin() failed)");
        bmp280_detected = false;
      } else {
        Serial.println("BMP280 initialized at 0x77");
      }
    } else {
      Serial.println("BMP280 initialized at 0x76");
    }

    if (bmp280_detected) {
      bmp280.setSampling(Adafruit_BMP280::MODE_NORMAL,
                         Adafruit_BMP280::SAMPLING_X2,
                         Adafruit_BMP280::SAMPLING_X16,
                         Adafruit_BMP280::FILTER_X16,
                         Adafruit_BMP280::STANDBY_MS_500);
    }
  }

  g_sensors_ok = true;  // OK even with 0 sensors (no crash)
  Serial.println("=== Core 1 Setup Complete ===\n");
}

// ========== Core 0: Main Loop (Networking + MQTT) ==========
void loop() {
  loopCount++;
  swWdtFeed();

  // Tier 2: 10-minute periodic reboot
  if (millis() >= REBOOT_INTERVAL) {
    rebootWithReason("periodic_10min_reboot");
  }

  // Ethernet check
  if (!eth.connected()) {
    Serial.println("Ethernet disconnected");
    rebootWithReason("eth_disconnected");
  }

  // MQTT check
  if (!mqttClient.connected()) {
    Serial.println("MQTT disconnected, reconnecting...");
    connectMQTT();
  }
  mqttClient.loop();

  // Publish HA Discovery once sensors are ready (first loop after Core 1 setup)
  static bool ha_discovery_done = false;
  if (g_sensors_ok && !ha_discovery_done) {
    publishHADiscovery();
    ha_discovery_done = true;
  }

  // Wait for sensor data from Core 1
  if (g_data_ready) {
    // Core0: グローバル変数読み取り（Core1書き込みとの競合防止）
    noInterrupts();
    float co2 = g_co2;
    float scd41_temp = g_scd41_temp;
    float scd41_hum = g_scd41_hum;
    float sht40_temp = g_sht40_temp;
    float sht40_hum = g_sht40_hum;
    float pressure = g_pressure;
    float bmp280_temp = g_bmp280_temp;
    interrupts();

    // Build JSON payload - only include non-NAN fields
    JsonDocument doc;
    doc["house_id"] = houseId;
    doc["node_id"] = nodeId;
    if (!isnan(co2))          doc["co2"] = round(co2);
    if (!isnan(scd41_temp))   doc["temperature"] = round(scd41_temp * 100) / 100.0;
    if (!isnan(scd41_hum))    doc["humidity"] = round(scd41_hum * 10) / 10.0;
    if (!isnan(sht40_temp))   doc["sht40_temperature"] = round(sht40_temp * 100) / 100.0;
    if (!isnan(sht40_hum))    doc["sht40_humidity"] = round(sht40_hum * 10) / 10.0;
    if (!isnan(pressure))     doc["pressure"] = round(pressure * 10) / 10.0;
    if (!isnan(bmp280_temp))  doc["bmp280_temperature"] = round(bmp280_temp * 100) / 100.0;
    doc["uptime"] = millis() / 1000;

    char buffer[512];
    serializeJson(doc, buffer);

    Serial.printf("[%d] ", loopCount);
    if (!isnan(co2)) Serial.printf("CO2=%.0fppm ", co2);
    if (!isnan(scd41_temp)) Serial.printf("T=%.2fC ", scd41_temp);
    if (!isnan(scd41_hum)) Serial.printf("RH=%.1f%% ", scd41_hum);
    if (!isnan(pressure)) Serial.printf("P=%.1fhPa ", pressure);
    Serial.println();

    // MQTT publish
    if (mqttClient.publish(mqttTopic.c_str(), buffer)) {
      Serial.println("  Published to MQTT");
      mqttFailCount = 0;
    } else {
      Serial.println("  MQTT publish failed");
      mqttFailCount++;
      Serial.printf("  MQTT failures: %d/%d\n", mqttFailCount, MQTT_FAIL_THRESHOLD);

      if (mqttFailCount >= MQTT_FAIL_THRESHOLD) {
        rebootWithReason("mqtt_fail_count_exceeded");
      }

      connectMQTT();
    }

    g_data_ready = false;
  }

  delay(1000);
}

// ========== Core 1: Main Loop (Sensor Reading) ==========
void loop1() {
  if (!g_sensors_ok) {
    delay(5000);
    return;
  }

  // SCD41: read only if detected
  if (scd41_detected) {
    uint16_t error;
    char errorMessage[256];
    uint16_t co2_raw = 0;
    float temperature_raw = 0.0f;
    float humidity_raw = 0.0f;
    bool isDataReady = false;

    error = scd4x.getDataReadyStatus(isDataReady);
    if (error) {
      errorToString(error, errorMessage, 256);
      Serial.printf("SCD41 getDataReadyFlag error: %s\n", errorMessage);
    }

    if (isDataReady) {
      error = scd4x.readMeasurement(co2_raw, temperature_raw, humidity_raw);
      if (error) {
        errorToString(error, errorMessage, 256);
        Serial.printf("SCD41 readMeasurement error: %s\n", errorMessage);
      } else if (co2_raw != 0) {
        // Core1: グローバル変数書き込み（Core0読み取りとの競合防止）
        noInterrupts();
        g_co2 = co2_raw;
        g_scd41_temp = temperature_raw - SCD41_TEMP_OFFSET;
        g_scd41_hum = humidity_raw;
        interrupts();
      }
    }
  }

  // SHT40: read only if detected
  if (sht40_detected) {
    uint16_t error;
    char errorMessage[256];
    float sht40_temp_raw = 0.0f;
    float sht40_hum_raw = 0.0f;
    error = sht4x.measureHighPrecision(sht40_temp_raw, sht40_hum_raw);
    if (error) {
      errorToString(error, errorMessage, 256);
      Serial.printf("SHT40 measureHighPrecision error: %s\n", errorMessage);
    } else {
      // Core1: グローバル変数書き込み（Core0読み取りとの競合防止）
      noInterrupts();
      g_sht40_temp = sht40_temp_raw;
      g_sht40_hum = sht40_hum_raw;
      interrupts();
    }
  }

  // BMP280: read only if detected + sanity check
  if (bmp280_detected) {
    float p = bmp280.readPressure() / 100.0;  // Pa -> hPa
    float t = bmp280.readTemperature() - BMP280_TEMP_OFFSET;
    if (!isnan(p) && p > 300 && p < 1200) {
      // Core1: グローバル変数書き込み（Core0読み取りとの競合防止）
      noInterrupts();
      g_pressure = p;
      g_bmp280_temp = t;
      interrupts();
    }
  }

  g_data_ready = true;

  delay(SENSOR_INTERVAL * 1000);
}

// ========== Configuration Functions ==========
void loadConfig() {
  if (LittleFS.exists("/config.json")) {
    File file = LittleFS.open("/config.json", "r");
    if (file) {
      JsonDocument doc;
      DeserializationError error = deserializeJson(doc, file);
      file.close();

      if (!error) {
        Serial.println("Config loaded from /config.json");
        houseId = doc["house_id"] | DEFAULT_HOUSE_ID;
        nodeId = doc["node_id"] | DEFAULT_NODE_ID;
        mqttBroker = doc["mqtt_broker"] | DEFAULT_MQTT_BROKER;
        mqttPort = doc["mqtt_port"] | DEFAULT_MQTT_PORT;
        mqttClientId = String("w5500-") + nodeId;
        mqttTopic = String("agriha/") + houseId + "/sensor/env/state";
        return;
      } else {
        Serial.printf("Config parse error: %s\n", error.c_str());
      }
    }
  }

  // Use defaults
  Serial.println("Using default configuration");
  houseId = DEFAULT_HOUSE_ID;
  nodeId = DEFAULT_NODE_ID;
  mqttBroker = DEFAULT_MQTT_BROKER;
  mqttPort = DEFAULT_MQTT_PORT;
  mqttClientId = String("w5500-") + nodeId;
  mqttTopic = String("agriha/") + houseId + "/sensor/env/state";
}

// ========== Ethernet Functions ==========
void initEthernet() {
  // HW Reset
  pinMode(W5500_RST, OUTPUT);
  digitalWrite(W5500_RST, LOW);
  delay(100);
  digitalWrite(W5500_RST, HIGH);
  delay(1000);

  // SPI0 pin config
  SPI.setSCK(18);
  SPI.setTX(19);   // MOSI
  SPI.setRX(16);   // MISO
  SPI.begin();

  // lwIP Ethernet
  lwipPollingPeriod(5);
  eth.begin();

  // DHCP wait
  Serial.println("Waiting for Ethernet DHCP...");
  unsigned long start = millis();
  while (!eth.connected()) {
    if (millis() - start > ETH_CONNECT_TIMEOUT * 1000UL) {
      Serial.println("Ethernet DHCP timeout");
      rebootWithReason("eth_dhcp_timeout");
    }
    delay(500);
    Serial.print(".");
  }

  Serial.println();
  Serial.printf("Ethernet connected: %s\n", eth.localIP().toString().c_str());
  Serial.printf("Subnet: %s\n", eth.subnetMask().toString().c_str());
  Serial.printf("Gateway: %s\n", eth.gatewayIP().toString().c_str());
}

// ========== MQTT Functions ==========
void connectMQTT() {
  for (int attempt = 0; attempt < MQTT_RECONNECT_ATTEMPTS; attempt++) {
    Serial.printf("MQTT attempt %d/%d: %s:%d\n",
                  attempt + 1, MQTT_RECONNECT_ATTEMPTS,
                  mqttBroker.c_str(), mqttPort);

    if (mqttClient.connect(mqttClientId.c_str())) {
      Serial.println("MQTT connected");
      // WA-4: OTA封印 — arduino-pico #3382 RP2350ブリックバグ未修正のため無効化
      // mqttClient.subscribe((String("agriha/") + nodeId + "/ota/trigger").c_str());
      return;
    }

    Serial.printf("MQTT connect failed, state=%d\n", mqttClient.state());
    if (attempt < MQTT_RECONNECT_ATTEMPTS - 1) {
      delay(MQTT_RECONNECT_DELAY * 1000);
    }
  }

  Serial.println("MQTT connection failed after retries");
  rebootWithReason("mqtt_connect_failed");
}

void publishHADiscovery() {
  const char* DISCOVERY_PREFIX = "homeassistant";
  String deviceId = String("w5500_env_node_") + nodeId;

  // Device info
  JsonDocument deviceDoc;
  JsonArray identifiers = deviceDoc["identifiers"].to<JsonArray>();
  identifiers.add(deviceId);
  deviceDoc["name"] = String("Env Node ") + nodeId;
  deviceDoc["model"] = "W5500-EVB-Pico2";
  deviceDoc["manufacturer"] = "DIY";
  deviceDoc["sw_version"] = FW_VERSION;

  int published = 0;
  for (int i = 0; i < HA_FIELDS_SIZE; i++) {
    // Only publish fields for detected sensors
    bool publish = false;
    switch (HA_FIELDS[i].source) {
      case SENSOR_SCD41:  publish = scd41_detected; break;
      case SENSOR_SHT40:  publish = sht40_detected; break;
      case SENSOR_BMP280: publish = bmp280_detected; break;
      default: break;
    }
    if (!publish) continue;

    String uid = deviceId + "_" + HA_FIELDS[i].key;
    String topic = String(DISCOVERY_PREFIX) + "/sensor/" + uid + "/config";

    JsonDocument doc;
    doc["name"] = HA_FIELDS[i].name;
    doc["stat_t"] = mqttTopic;
    doc["uniq_id"] = uid;
    doc["val_tpl"] = String("{{ value_json.") + HA_FIELDS[i].key + " }}";
    doc["unit_of_meas"] = HA_FIELDS[i].unit;
    doc["dev_cla"] = HA_FIELDS[i].dev_class;
    if (HA_FIELDS[i].icon) {
      doc["ic"] = HA_FIELDS[i].icon;
    }
    doc["dev"] = deviceDoc;

    char buffer[768];
    serializeJson(doc, buffer);
    mqttClient.publish(topic.c_str(), buffer, true);
    Serial.printf("HA Discovery: %s\n", topic.c_str());
    delay(500);
    published++;
  }

  Serial.printf("HA MQTT Auto Discovery published (%d sensors)\n", published);
}

// ========== Reboot Function ==========
void rebootWithReason(const char* reason) {
  Serial.printf("Rebooting: %s\n", reason);

  File file = LittleFS.open("/reboot_reason.txt", "w");
  if (file) {
    file.print(reason);
    file.close();
  }

  delay(2000);
  watchdog_reboot(0, 0, 0);
}

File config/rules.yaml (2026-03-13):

# Layer 2: ルールベース制御設定
temperature:
  target_day: 26.0             # 日中目標温度 (℃)
  target_night: 17.0           # 夜間目標温度 (℃) ※LOW_TEMP_THRESHOLD(16℃)+1℃以上を推奨
  margin_open: 2.0             # 目標+Nで窓開 (℃)
  margin_close: 1.0            # 目標-Nで窓閉 (℃)
  attention_temp: 30.0         # 注意ライン (℃) P90相当: 全窓70-100%開放
  emergency_temp: 32.0         # 緊急ライン (℃) P95相当: 全窓全開
  early_morning_offset: -1.0   # 早朝5-8h換気先行オフセット (℃): 通常閾値より1℃早く換気開始
  # window_channels は channel_map.yaml の side_window.groups に集約（open/close分離）

wind:
  strong_wind_threshold_ms: 5.0  # 強風閾値 (m/s)
  # 風向別の窓閉判定は channel_map.yaml の side_window.groups[].wind_close_directions に集約

rain:
  threshold_mm_h: 0.5           # 降雨閾値 (mm/h)
  resume_delay_min: 30          # 降雨停止後の再開猶予 (分)

irrigation:
  channel: 4                    # 灌水電磁弁チャンネル
  crop_config_path: "/etc/agriha/crop_irrigation.yaml"

unipi_api:
  base_url: "http://localhost:8080"
  api_key: ""
  timeout_sec: 10

location:
  latitude: 42.888
  longitude: 141.603
  elevation: 21

pitagorasu:
  enabled: true                   # false=従来のバイナリ開閉にフォールバック
  open_travel_sec: 65             # 全閉→全開 走行時間（巻き上げ、重力に逆らう）
  close_travel_sec: 50            # 全開→全閉 走行時間（巻き下ろし、重力アシスト）
  deadband: 0.05                  # 不感帯（5%未満の差分は無視）
  stages:                         # max_temp昇順。effective_temp < max_temp で判定
    - {max_temp: 25.0, south: 0.0, north: 0.0, name: closed}
    - {max_temp: 27.0, south: 0.3, north: 0.0, name: south_micro}
    - {max_temp: 30.0, south: 0.5, north: 0.5, name: both_medium}
    - {max_temp: 32.0, south: 0.8, north: 0.8, name: both_wide}
    - {max_temp: 999,  south: 1.0, north: 1.0, name: full_open}
  predictive:
    mild_trend_threshold: 1.5     # ℃/h 以上で先読み補正
    rapid_trend_threshold: 3.0    # ℃/h 以上で大幅先読み
    mild_bonus: 1.0               # mild時の実効温度加算 (℃)
    rapid_bonus: 2.0              # rapid時の実効温度加算 (℃)

custom_rules: []

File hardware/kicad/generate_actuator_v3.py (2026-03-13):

#!/usr/bin/env python3
"""
Pico 2 W アクチュエータノード基板 - 回路図自動生成スクリプト
Version: 3.0
Created: 2026-02-08

4ch リレー駆動基板
各チャンネル: GPIO → R(330Ω) → PC817 → R(100Ω) → 2N7002(Gate)
              2N7002(Drain) → リレーコイル → 5V
              + フライバックダイオード + プルダウン + LED

レイアウト:
  上部: Pico ピンヘッダ (J1左, J2右)
  中段: 4ch フォトカプラ+MOSFET+リレー (横並び)
  下段: 出力端子台 (J3-J6) + 電源コンデンサ
"""

import sys
import os
import re
from pathlib import Path

sys.path.insert(0, "/home/yasu/unipi-agri-ha/.venv/lib/python3.12/site-packages")
import kicad_sch_api as ksa

os.environ["KICAD_SYMBOL_DIR"] = "/home/yasu/unipi-agri-ha/hardware/kicad/kicad-symbols"

output_dir = Path("/home/yasu/unipi-agri-ha/hardware/kicad")

print("=== Actuator Board v3 - 4ch Relay Driver ===\n")

try:
    sch = ksa.create_schematic("Pico 2W Actuator Board")
    sch.set_title_block(
        title="Pico 2W Actuator Board - 4ch Relay",
        date="2026-02-08",
        rev="3.0",
        company="AgriHA Project"
    )

    # =========================================================================
    # レイアウト定数 (mm) - A4横: 297 x 210mm
    # =========================================================================

    # --- Pico Headers (上部) ---
    PICO_Y = 30.0
    J1_X = 40.0       # 左ヘッダ
    J2_X = 80.0        # 右ヘッダ (近く配置、ほとんどNCなので)

    # --- チャンネル配置 (中段 横並び) ---
    CH_START_X = 120.0  # CH0開始X
    CH_SPACING = 40.0   # チャンネル間隔
    CH_Y_PHOTOCOUPLER = 35.0   # フォトカプラ行
    CH_Y_MOSFET = 75.0         # MOSFET行
    CH_Y_RELAY = 110.0         # リレー行
    CH_Y_TERMINAL = 150.0      # 端子台行

    # --- 電源 (右下) ---
    PWR_X = 40.0
    PWR_Y = 150.0

    # チャンネル名
    CH_NAMES = ["Irri", "Valve", "VenFan", "Relay"]
    # 対応GPIO (Pico Left header の pin番号)
    # GP10=J1 pin14, GP11=J1 pin15, GP12=J1 pin16, GP13=J1 pin17
    CH_GPIO_PINS = ["14", "15", "16", "17"]

    # =========================================================================
    # 1. コンポーネント配置
    # =========================================================================
    print("[1] Adding components...")

    # --- Pico Headers ---
    j1 = sch.components.add(
        lib_id="Connector_Generic:Conn_01x20",
        reference="J1", value="Pico_Left",
        position=(J1_X, PICO_Y), rotation=0.0
    )
    j2 = sch.components.add(
        lib_id="Connector_Generic:Conn_01x20",
        reference="J2", value="Pico_Right",
        position=(J2_X, PICO_Y), rotation=0.0
    )
    print("  Pico Headers (J1, J2)")

    # --- 電源コンデンサ ---
    c1 = sch.components.add(
        lib_id="Device:C_Polarized", reference="C1", value="100u",
        position=(PWR_X, PWR_Y), rotation=0.0
    )
    c2 = sch.components.add(
        lib_id="Device:C", reference="C2", value="100n",
        position=(PWR_X + 12, PWR_Y), rotation=0.0
    )
    # 外部電源端子
    j7 = sch.components.add(
        lib_id="Connector_Generic:Conn_01x02",
        reference="J7", value="5V_EXT",
        position=(PWR_X + 25, PWR_Y), rotation=0.0
    )
    print("  Power caps (C1, C2) + J7")

    # --- 4チャンネル繰り返し ---
    for ch in range(4):
        cx = CH_START_X + ch * CH_SPACING  # チャンネルのX位置
        n = ch + 1  # 1-based index

        # フォトカプラ入力抵抗 (R13-R16: 330Ω, GPIO → PC817 LED)
        sch.components.add(
            lib_id="Device:R", reference=f"R{12+n}", value="330",
            position=(cx, CH_Y_PHOTOCOUPLER), rotation=0.0
        )

        # フォトカプラ (U2-U5: PC817)
        sch.components.add(
            lib_id="Isolator:PC817", reference=f"U{1+n}", value="PC817",
            position=(cx, CH_Y_PHOTOCOUPLER + 18), rotation=0.0
        )

        # ゲート抵抗 (R1-R4: 100Ω)
        sch.components.add(
            lib_id="Device:R", reference=f"R{n}", value="100",
            position=(cx, CH_Y_MOSFET - 5), rotation=0.0
        )

        # プルダウン抵抗 (R5-R8: 10kΩ)
        sch.components.add(
            lib_id="Device:R", reference=f"R{4+n}", value="10k",
            position=(cx + 8, CH_Y_MOSFET + 5), rotation=0.0
        )

        # MOSFET (Q1-Q4: 2N7002)
        sch.components.add(
            lib_id="Device:Q_NMOS_GSD", reference=f"Q{n}", value="2N7002",
            position=(cx + 15, CH_Y_MOSFET), rotation=0.0
        )

        # フライバックダイオード (D1-D4: 1N4148)
        sch.components.add(
            lib_id="Device:D", reference=f"D{n}", value="1N4148",
            position=(cx + 22, CH_Y_RELAY - 5), rotation=90.0
        )

        # LED電流制限抵抗 (R9-R12: 330Ω)
        sch.components.add(
            lib_id="Device:R", reference=f"R{8+n}", value="330",
            position=(cx + 28, CH_Y_MOSFET), rotation=0.0
        )

        # インジケータLED (LED1-LED4)
        sch.components.add(
            lib_id="Device:LED", reference=f"LED{n}", value="Red",
            position=(cx + 28, CH_Y_MOSFET + 12), rotation=0.0
        )

        # リレー (K1-K4) - 汎用リレーシンボルとして Conn_01x02 (コイル側)
        sch.components.add(
            lib_id="Relay:SANYOU_SRD_Form_C", reference=f"K{n}", value=CH_NAMES[ch],
            position=(cx + 15, CH_Y_RELAY), rotation=0.0
        )

        # 出力端子台 (J3-J6: NO/COM/NC)
        sch.components.add(
            lib_id="Connector_Generic:Conn_01x03",
            reference=f"J{2+n}", value=f"OUT_{CH_NAMES[ch]}",
            position=(cx + 15, CH_Y_TERMINAL), rotation=0.0
        )

        print(f"  CH{ch} ({CH_NAMES[ch]}): R{12+n}, U{1+n}, R{n}, R{4+n}, Q{n}, D{n}, R{8+n}, LED{n}, K{n}, J{2+n}")

    # =========================================================================
    # 2. ネットラベル
    # =========================================================================
    print("\n[2] Adding net labels...")
    sch.add_label(text="3V3", position=(J2_X + 15, PICO_Y + 38))
    sch.add_label(text="GND", position=(J1_X - 10, PICO_Y + 5))
    sch.add_label(text="VSYS", position=(J2_X + 15, PICO_Y + 46))
    print("  Added power labels")

    # =========================================================================
    # 3. ワイヤー接続
    # =========================================================================
    print("\n[3] Adding wire connections...")

    wire_count = 0

    def add_wire(ref1, pin1, ref2, pin2, label=""):
        global wire_count
        try:
            sch.add_wire_between_pins(ref1, pin1, ref2, pin2)
            wire_count += 1
        except Exception as e:
            print(f"  WARN: {label}: {ref1}.{pin1} → {ref2}.{pin2}: {e}")

    # --- 各チャンネルの配線 ---
    for ch in range(4):
        n = ch + 1
        gpio_pin = CH_GPIO_PINS[ch]  # J1のピン番号

        # === 1次側 (3.3V制御) ===
        # GPIO → R13-16(pin1) フォトカプラ入力抵抗
        add_wire("J1", gpio_pin, f"R{12+n}", "1", f"CH{ch} GPIO→R")

        # R13-16(pin2) → U2-5(pin1) フォトカプラ LED アノード
        add_wire(f"R{12+n}", "2", f"U{1+n}", "1", f"CH{ch} R→PC817 anode")

        # U2-5(pin2) → GND  フォトカプラ LED カソード
        add_wire(f"U{1+n}", "2", "J1", "3", f"CH{ch} PC817 cathode→GND")

        # === 2次側 (5V リレー駆動) ===
        # U2-5(pin4) → 5V (VSYS)  フォトカプラ コレクタ
        add_wire(f"U{1+n}", "4", "J2", "19", f"CH{ch} PC817 collector→5V")
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

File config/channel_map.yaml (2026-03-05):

# config/channel_map.yaml
# チャンネル割当設定 — 農家ごとにカスタマイズ可能
# v4 spec準拠: ch5=北開, ch6=北閉, ch7=南閉, ch8=南開（実測確認済み）
#
# ■ 用途:
#   UniPiリレーch番号と制御機器のマッピングを定義する。
#   agriha_chat.py・rule_engine・forecast_engine・plan_executor等が
#   このファイルを参照してラベル表示・制御判断を行う。
#   ソースコードにch番号をハードコードしないための外部設定ファイル。
#
# ■ カスタマイズ手順:
#   1. 本ファイルを編集（リポジトリ: config/channel_map.yaml）
#   2. デプロイ: sudo cp config/channel_map.yaml /etc/agriha/channel_map.yaml
#   3. agriha-chatサービス再起動: sudo systemctl restart agriha-chat
#   ※ 制御スクリプト(emergency_guard/rule_engine/forecast_engine/plan_executor)は
#      cronジョブのため再起動不要。次回cron実行時に自動反映。
#   ※ 実機のリレー配線を変更した場合、このファイルも合わせて更新すること
#
# ■ フィールド説明:
#   irrigation: 灌水ポンプのch番号とラベル
#   side_window.groups: 側窓グループ（窓ごとに開チャンネル・閉チャンネルを分離定義）
#     - name: グループ名（ログ・UI表示用）
#     - open_channel: 窓を開けるリレーch番号
#     - close_channel: 窓を閉めるリレーch番号
#     - wind_close_directions: この窓を閉める強風方角コード（MISOL wind_direction値）
#   relay_labels: ch1-8の表示ラベル一覧（WebUI・ログ表示用）
#   valid_channels: 有効ch番号の範囲（バリデーション用）
#
# デプロイ先: /etc/agriha/channel_map.yaml
# リポジトリ: config/channel_map.yaml（fallback）

irrigation:
  channel: 4
  label: "灌水ポンプ"

side_window:
  groups:
    - name: "北側窓"
      open_channel: 5
      close_channel: 6
      wind_close_directions: [1, 2, 16]
    - name: "南側窓"
      open_channel: 8
      close_channel: 7
      wind_close_directions: [8, 9, 10]

relay_labels:
  1: "暖房"
  2: "循環扇"
  3: "CO2発生器"
  4: "灌水ポンプ"
  5: "北側窓(開)"
  6: "北側窓(閉)"
  7: "南側窓(閉)"
  8: "南側窓(開)"

valid_channels:
  min: 1
  max: 8

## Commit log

2026-02-22 Initial commit: uecs-llm public repository
    LLM-based greenhouse environment control with UECS-CCM integration.
    Extracted from unipi-agri-ha (private) with sanitized configs,
    relative imports, and 225 passing tests.
    Components:
    - uecs_llm: LLM control loop (agriha_control.py)
    - unipi_daemon: Hardware daemon (I2C, GPIO, MQTT, REST)
    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
2026-02-22 feat: tmux セッション起動スクリプト + LLM対話シェル
    5ペイン構成:
    - llama-server / unipi-daemon / MQTT監視 / journalctl / LLM Chat
2026-02-22 fix: tmux 3.4 互換 — split時のサイズ指定を除去、レイアウト修正
2026-02-22 fix: tmux構成をnuc実態に合わせ修正、llm-chatをPython化
    - llama-serverはsystemd稼働中なのでログ表示に変更
    - unipi-daemonはRPi側なのでagriha-controlログに変更
    - MQTTはRPi(10.10.0.10)に接続
    - REST API監視ペイン追加（センサー+ステータス定期取得）
    - llm-chat.sh: bash+json地獄からPythonに書き換え
2026-02-22 fix: mosquitto listener を 0.0.0.0 にbind（VPN経由接続許可）
    Mosquitto 2.x はlistener未指定だとlocalhostのみ。
    nuc→RPi間のVPN経由MQTT接続に必要。
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2026-02-22 feat: VPS クラウドサーバー構成 (InfluxDB + Telegraf + Grafana + LINE Bot)
    cloud/ ディレクトリに Docker Compose 一式を追加。
    Telegraf は WireGuard VPN 経由で RPi の MQTT に接続し、
    センサーデータを InfluxDB に蓄積、Grafana で可視化・LINE アラート通知。
    README に LINE API 認証情報の取得手順を追加。
2026-02-22 fix: alerting.yaml の環境変数名を .env.example と統一
    LINE_CHANNEL_TOKEN → LINE_CHANNEL_ACCESS_TOKEN に修正。
    不一致のままだと Grafana の LINE アラート通知が失敗する。
2026-02-22 feat: インフラ設定ファイル整合性テスト (tests/infra/)
    docker-compose, telegraf, grafana, mosquitto, .env.example 間の
    bucket名・org名・datasource UID・環境変数名・ポート設定の
    クロスファイル整合性を pytest で自動検証する。22テスト。
    今回の mosquitto 0.0.0.0 問題や LINE_CHANNEL_TOKEN 不一致のような
    設定ファイル間のズレを事前に検知できる。
2026-02-22 fix: align configs with production deployment
    - telegraf.conf: replace greenhouse/# with 5 individual MQTT consumers
    matching actual agriha/ topic structure (ccm_sensor, ccm_control,
    ds18b20, relay_state, weather_misol)
    - dashboard: update Flux queries to actual measurements/bucket,
    add camera panel, remove dead irrigation history panels
    - alerting.yaml: update measurement names and tag keys
    - docker-compose: add camera-web nginx service
    - .env.example: add CAMERA_IMAGE_DIR and CAMERA_URL
    - Add image/camera_upload.sh for RPi camera capture + scp
    - tests: add dashboard-telegraf measurement alignment tests,
    camera script existence test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
2026-02-23 feat: 日時+日の出/日没注入機能 (cmd_260-263)
    agriha_control.py: astral>=3.2 で日の出/日没計算、get_sun_times()/get_time_period() 追加。
    run_control_loop() の user message 冒頭に現在日時・日の出・日没・時間帯を注入。
    scripts/llm-chat.sh: _datetime_header() 追加。各 user message に日時情報を自動注入。
    tests/llm_control/: TestSunTimes(9) + TestDatetimeInjection(6) 追加、conftest.py 新規。
    docs/llm_control_loop_design.md: v2.1 §13 日時注入仕様追記。
    system_prompt.txt: 栽培期間5月-11月を追記。
2026-03-01 feat: Layer 3 forecast_engine.py + pytest tests (cmd_286)
    - forecast_engine.py: Claude Haiku API で1時間予報計画を生成
    - lockout中は計画生成スキップ (殿裁定 MAJOR-2)
    - set_relay除外 (計画生成のみ、リレー操作はplan_executor担当)
    - スキーマ検証 (relay_ch, value, duration_sec, execute_at)
    - agriha_control.py ベースの発展的移行
    - config/layer3_config.yaml: 設計書§6.3準拠
    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
2026-03-01 feat: Layer 2 rule_engine.py + pytest tests (cmd_286)
    - src/v2_control/rule_engine.py: Layer 2ガムテ制御実装
    - Step1-8の処理フロー（設計書§1.2に準拠）
    - 降雨/強風/夜間/温度/日射比例灌水の5ルール
    - Layer1ロックアウト・CommandGateロックアウト確認
    - Layer3計画(current_plan.json)参照・温度制御委譲
    - solar_accumulator.json・rule_engine_state.json更新
    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
2026-03-01 feat: plan_executor.py + pytest tests (cmd_286)
    - src/v2_control/plan_executor.py: Layer 3補助 実装 (~160行)
    - Step 1: current_plan.json 読み込み（なし/期限切れ → 終了）
    - Step 2: Layer1/CommandGateロックアウト確認
    - Step 3: 降雨/強風チェック（殿裁定MAJOR-3: 下層が上層を黙らせる原則）
    - rainfall > threshold or wind_speed > threshold → 側窓操作をskipped_weather
    - 閾値はlayer2_config.yamlから参照（重複定義回避）
    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
2026-03-01 feat: Layer 1 emergency_guard.sh + bats tests (cmd_286)
    - src/v2_control/emergency_guard.sh: POSIX sh互換 緊急停止スクリプト
    - layer1.env読み込み (AGRIHA_CONFIG/LOCKOUT/LOGで上書き可)
    - Step1a: Layer 1自身のロックアウト確認 (lockout_state.json)
    - Step1b: CommandGate ロックアウト確認 (GET /api/status)
    - Step2: センサーデータ取得 (GET /api/sensors)
    - Step3: CCM InAirTemp優先、Misolフォールバック
    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
2026-03-01 feat: agriha_ui backend - FastAPI routes + config (cmd_287)
    - src/agriha_ui/app.py (~210行): FastAPI + Jinja2 + Basic Auth
    - GET / → dashboard.html (sensors/lockout/rule_engine/forecast/relays)
    - GET /api/dashboard-partial → htmx部分更新用
    - GET /settings → settings.html (thresholds + system_prompt編集)
    - POST /settings/prompt → system_prompt.txt保存 (バックアップ付き)
    - POST /settings/thresholds → thresholds.yaml保存 (バリデーション付き)
    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
2026-03-01 feat: agriha_ui templates + CSS (cmd_287)
    Jinja2 + htmx によるRPiローカルWebUIフロントエンド実装
    - src/agriha_ui/templates/base.html: 共通レイアウト（ナビ・フッター）
    - src/agriha_ui/templates/dashboard.html: ダッシュボード
    - htmx自動更新 (hx-get=/api/dashboard-partial every 10s)
    - センサーカードグリッド（動的キー対応）
    - 三層制御状態表示（Layer1/2/3）
    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
2026-03-01 test: agriha_ui pytest全ルートテスト (cmd_287)
    12テストケース全件PASS:
    - GET / ダッシュボード（正常・API不達）
    - GET /api/dashboard-partial
    - GET /settings（正常・prompt不在）
    - POST /settings/prompt（保存・バックアップ）
    - POST /settings/thresholds（保存・不正値バリデーション）
    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
2026-03-01 fix: agriha_ui pytest test_5/10/11 モック修正 (cmd_287 rework)
    Pythonのデフォルト引数はimport時評価のため
    patch.object(module変数)はデフォルト引数に効かない。
    3件を関数パッチ方式に修正:
    - test_5: patch.object(SYSTEM_PROMPT_PATH) → patch(load_system_prompt, return_value="")
    - test_10: patch.object(CONTROL_LOG_DB) → patch(query_decisions, mock_decisions)
    assertも実データ（緊急開窓/灌水ON）で検証
    - test_11: patch.object(CONTROL_LOG_DB) → patch(query_decisions, return_value=[])
    assert「制御履歴はありません」で空リスト表示を確認
2026-03-01 fix: rename check_ollama_health → check_llm_health in linebot/app.py (cmd_288)
2026-03-01 docs: gradient_controller設計追記 — 勾配制御層+3軸ゲイン+病害リスクスコア (cmd_293)
    - §3.6 gradient_controller（勾配制御層）新設: forecast_engine→rule_engine間の動的パラメータ調整
    - §3.6.1 3軸ゲイン（気温・湿度・CO2）: priority重み配分、目標付近ソフトランディング、変化率制限
    - §3.6.2 病害リスクスコア: dew_hours/dry_hours仮実装、差し替え可能インターフェース定義
    - §3.6.3 LLM予報フォーマット改訂: target/priority/overrides/reason を§3.3 actionsと併存
    - §3.2 定時予報ループにStep 5.5（gradient_controllerパラメータ調整）追記
    - 概要システム全体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
2026-03-02 docs: cmd_295 cross-consistency fix (subtask_676)
    3ファイル整合性修正:
    - system_prompt.txt: temp_setpoint_day/night → temp_setpoint 統一
    - v2_three_layer_design.md: pid_override.jsonスキーマをllm_control_loop準拠に統一
    (trigger_reason→trigger, target_temp→pid_targets.temp_setpoint,
    gains_override→pid_gains_override, summary→reason, confidence追加)
    - llm_control_loop_design.md: スクリプト名対応表追加、図中名称更新
    (pid_controller.py→rule_engine.py, agriha_control.py→forecast_engine.py,
    cron毎分→5分毎)
2026-03-02 docs: cmd_295 殿裁定反映 — PIDスケール明記+符号統一+変換レイヤー (subtask_677)
    (A) PIDゲインスケール明記:
    - llm §3.6.1: ゲインテーブルに「温度偏差→デューティ比(0.0-1.0)スケール」注記
    - v2 GAIN_TABLE: 「温度偏差→duration_sec(0-60秒)スケール」注記
    - 両設計書間のKp値差(1.5 vs 8.0)はスケール差であり矛盾ではない旨を明記
    (B) PIDエラー符号をcurrent-targetに統一:
    - llm §3.2処理フロー: 「目標気温-実測気温」→「実測気温-目標気温 (current-target)」
    - llm §3.6位置づけ図: error=setpoint-actual → error=actual-setpoint
    - llm §3.6.1 概念コード: pid_step内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
2026-03-03 fix: is_layer1_locked() now引数追加でテスト修復 (cmd_298)
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2026-03-04 docs: v4仕様書移行+お針子指摘4点修正（unipi-agri-haから仕様書のみコピー）
    - agriha_v4_spec.md, agriha_v4_spec_part2.md を unipi-agri-ha から移行
    - 修正1: unipi-daemon ファイル数 9→10ファイル (audit_094確認済み)
    - 修正2: search_query「晴」→「Clear」(Visual Crossing API英語仕様に統一)
    - 修正3: §9.4 plan_executor.py 参照箇所テーブルに追記 (commit 907259e確認済み)
    - 修正4: §9.6 deployコマンドから agriha-control 削除+cronジョブ注記追加
2026-03-04 refactor: v4ディレクトリ再構築 — src/agriha/パッケージ化+tests統一+全importパス修正
    [ccm_receiver.py, ds18b20.py, emergency_override.py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]
2026-03-04 fix: agriha-cron頻度修正 — rule_engine */5→*/10, plan_executor 毎分→*/10（仕様書§5.2準拠）
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2026-03-04 fix: agriha-ui.service ポート8502→8501（殿裁定準拠）
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2026-03-04 refactor: 全ソース設定パス参照修正(layer1→emergency, layer2→rules, layer3→forecast)
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2026-03-04 feat: rule_engine flag書き出し+plan_executor flag読み込み（§3.4層間連携）
    rule_engine.py:
    - FLAG_DIR定数追加（AGRIHA_FLAG_DIR環境変数で上書き可能）
    - update_weather_flags()追加: 降雨/強風時にrain_flag/wind_flagを書き出し、解除時に削除
    - run()にflag_dir引数追加、センサー取得後に自動実行
    plan_executor.py:
    - FLAG_DIR/FLAG_MAX_AGE_SEC定数追加
    - is_flag_active()追加: mtimeが20分以内のflagのみ有効と判定
    - Step 3をセンサーAPI直接呼び出しからflagファイル読み込みに変更
    - action["executed"]: "skipped_weather" → "skipped_rain"/"skipped_wind" に細分化
    - skipped_already_done判定を新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
2026-03-04 feat: 高札API検索+LLMスキップ判定+plan生成+search_log（§3.3+§7準拠）
    - search_kousatsu(): urllib経由で高札API検索（タイムアウト/エラー時は空返却）
    - should_skip_llm(): total_hits>=3でLLMスキップ判定
    - build_plan_from_search_results(): 検索結果snippetからcurrent_plan.json生成
    - convert_llm_to_pid_override(): dewpoint_risk→pid_override.json変換
    - log_search(): search_log.jsonlにjsonl追記
    - run_forecast() Step 4.5統合: センサー先行取得→高札検索→skip_llm判定→LLMorKousatsu分岐
    - テスト追加: Test34-48（15件、46/46 PASS→344/344 PASS）
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2026-03-04 feat: distiller.py蒸留パイプライン(search_log頻度分析+ルール候補生成, N=7/conf≥0.80)
    - distiller.py新規作成: load_search_log/analyze_frequency/extract_typical_actions/generate_candidates/save_candidates/run_distill
    - 閾値: frequency≥7, confidence≥0.80(kousatsu_rate)
    - rule_candidates.yaml出力(pending/expired管理+30日EXPIRY)
    - systemd/agriha-cron: 週次バッチ追加(月曜03:00)
    - テスト: test_distiller.py新規15件、全378件PASS
    - fix: test_app.py flags APIキー名修正(rain_flag→rain, wind_flag→wind, §3.5準拠)
2026-03-04 fix: audit指摘3件修正(/api/dashboard relay/logs追加+flags名統一+co2_mode変換)
    - app.py: fetch_relay()追加、/api/dashboard に relay/logs フィールド追加（§3.5準拠）
    - app.py: _get_flags_data() のキー名を rain_flag→rain, wind_flag→wind に統一（§3.5準拠）
    - forecast_engine.py: convert_llm_to_pid_override() に co2_mode→co2_setpoint 変換追加
    （ventilate=400, accumulate=700, neutral=550、§7準拠）
    - テスト: flags名テスト2件・dashboard relayフィールドテスト1件・co2_modeパラメトリックテスト5件追加
    381/381 PASS
2026-03-04 fix: audit_108指摘修正(cron .venvパス+generate_candidates id付与)
2026-03-04 feat: reflection.py反省会コア(候補選定+質問生成+回答処理+reflection_memoテーブル)+config/reflection.yaml
    - config/reflection.yaml: weekly/月曜07:00/max_items=3/nag=2週/downgrade=4週
    - src/agriha/control/reflection.py: load_config/select_candidates/generate_question/
    create_reflection_memos/process_answer/check_nag_status/run_reflection
    - forecast_engine.py init_db(): reflection_memoテーブル追加
    - systemd/agriha-cron: 反省会cron追加 (月曜07:00, 蒸留4時間後)
    - tests/control/test_reflection.py: 16件 402/402 PASS
    fix: check_nag_status since-filterバグ修正 (未回答メモ全件から最古を検索する方式に変更)
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2026-03-04 fix: systemdパス__REPO_DIR__化+setup.sh sed置換+.env.example VC API KEY追加
2026-03-04 fix: setup.sh VENV_DIR venv→.venv修正 (audit_113)
2026-03-04 fix: /opt/agriha配置対応(setup.sh手順+README+cron+log dir)
2026-03-04 fix: setup.sh chown+enable完結化+README 3ステップ圧縮(農家UX)
2026-03-04 fix: pyproject.toml依存漏れ全修正(jinja2/python-multipart/astral)
2026-03-04 fix: pyproject.tomlにanthropic>=0.20追加(遅延import漏れ, audit_116)
2026-03-04 fix: Jinja2 'not in' テストエラー修正 — selectattr→forループに変更
    Jinja2にはselectattr('0', 'not in', ...)テストが存在しない。
    Pi4実機デプロイで TemplateRuntimeError: No test named 'not in' 発生。
2026-03-04 fix: ダッシュボードセンサー表示修正 — キーマッピング+二重ネスト解消
    1. fetch_sensors()がunipi-daemon APIの{"sensors":{...}}を展開せず
    二重ネストでテンプレートに渡していた問題を修正
    2. テンプレートのセンサーキーを実データに合わせて修正:
    - agriha/h01/ccm/InAirTemp → agriha/1/ccm/sensor/InAirTemp
    - .value → ['value'] (dict access)
    3. 外気温・風速・露点・積算日射カードを追加
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2026-03-04 fix: cron .env読み込み追加 + VC_API_KEY変数名統一
    1. agriha-cronの全Python行に `. .env &&` を追加し、
    ANTHROPIC_API_KEY等の環境変数をcron実行時にも読み込む
    2. パスプレースホルダーを__REPO_DIR__に統一（setup.shのsed対象）
    3. .env.exampleのVISUAL_CROSSING_API_KEY→VC_API_KEYに修正
    （forecast_engine.pyが参照する変数名と一致させる）
2026-03-04 fix: .env.example に export 追加 — cron経由でPython os.environ に渡るように
2026-03-04 fix: 全ファイルCRLF→LF変換 + .gitattributes追加でLF強制
    cronがCRLFで"bad username"エラー、.envもCRLFでexportが効かない問題を根本解決。
    [ccm_receiver.py, channel_map.yaml, ds18b20.py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]
2026-03-04 feat: 計画タイムラインをダッシュボードに追加
    - _build_plan_timeline() で current_plan.json からガントチャート用データ算出
    - dashboard.html / dashboard_partial.html に計画タイムラインsection追加
    - ステータス色分け: 予定(青)/実行済(緑)/雨スキップ(橙)/風スキップ(黄)/期限切れ(赤)
    - 現在時刻マーカー(赤縦線)、レスポンシブ対応(768px以下)
    - dashboard_partial.html バグ修正3件(センサーキー不一致/selectattr/dict access)
    - リレー状態にchannel_map.yamlのラベル表示を追加
    - テスト11件追加(438 passed)
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2026-03-05 fix: setup.sh ダッシュボード編集対象ファイルの権限設定追加
    新規インストール時に /etc/agriha/ の設定ファイルが root:root になり
    ダッシュボードから保存できない問題を修正。
    agrihaユーザー作成後にchown+chmod 664を実行する。
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2026-03-05 fix: .env export形式対応 — read_env_file/write_env_keyがexport KEY=valueを正しく処理
    RPiの.envファイルはexport付き形式だが、read_env_fileが未対応だったためAPIキー状態が
    「未設定」と表示される問題を修正。write_env_keyもexportプレフィックスを維持するよう改修。
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2026-03-06 fix: forecast_engine api_key変数名衝突修正 — unipi用api_key/LLM用llm_api_keyに分離 (audit指摘)
2026-03-06 fix: agriha-nullclaw-proxy.service venv→システムuvicorn+WorkingDirectory追加 (RPi実機対応)
2026-03-06 fix: save系関数のrename→write_text上書きに変更 — /etc配下ディレクトリ権限エラー修正 (cmd_336)
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2026-03-06 docs: §3.9 APN修正 — さくら削除・デフォルトをsoracom.ioに変更 (cmd_339/subtask_771)
    - キャリアプリセット表からさくらのセキュアモバイルを削除
    - デフォルトプリセットをSORAC OM Air(soracom.io)に変更
    - UIモックアップ・nmcli例も同様に更新
    - 他キャリアは手動入力前提の注意書き追加
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2026-03-07 feat: settings画面にUSB SIM / APN設定UI実装 (cmd_350/subtask_787)
    - app.py:
    - APN_PRESETS定数追加 (SORACOM/IIJmio/手動入力)
    - load/save_network_config(): network.yaml 読み書き、ファイル不在時SOARCOMデフォルト
    - get_network_status(): mmcli/nmcliでドングル検出+IP取得、未インストール時graceful skip
    - GET /api/network/status: 接続状態APIエンドポイント
    - POST /settings/network/apn: APN設定保存エンドポイント
    - GET /settings: network_config/network_status/apn_presetsをコンテキストに追加
    - settings.html: ネットワーク設定セクション追加
    - 接続状態表示（セルラー/ドングル検出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
2026-03-07 feat: system_prompt.txt RPi逆同期＋CO2ルール重複整理 (cmd_351/subtask_788)
    【RPi実機修正の取り込み（殿の微調整）】
    - ハウス環境: 暖房ch1(ガス暖房)→なし、循環扇ch2→ch2,ch3、CO2発生器ch3→なし
    - CO2光合成効率低下閾値: 400〜600ppm → 300ppm
    - CO2換気完了判定: 800ppm以上 → 380ppm以上
    【構造整理（老中追加指示）】
    - ルール4タイトル修正: 「CO2換気はパルスでやれ」を分離
    - 番号なし2ブロック(因果関係+パルス換気)をルール5として統合
    - ルール番号欠番(4→6)を解消: ルール1-6の連番化
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2026-03-07 fix: setup.sh thresholds.yaml漏れ修正 (cmd_356/subtask_795)
    - L35 コピーループにconfig/thresholds.yamlを追加
    - L76 chownループにthresholds.yaml, network.yamlを追加
2026-03-07 fix: /etc/agriha権限根本修正+network.yaml初期テンプレ (cmd_357/subtask_796)
    - setup.sh: mkdir後にCONFIG_DIRのchown追加（agrihaユーザーが新規ファイル作成可能に）
    - setup.sh: L36コピーループにconfig/network.yamlを追加
    - config/network.yaml: SORACOMデフォルト値を持つテンプレート新規作成
2026-03-08 feat: WCAG2.1 AA Phase1A コントラスト+focus+skip+aria (cmd_359/subtask_798)
    - style.css: CSS変数コントラスト修正 (--color-muted/#--color-success/--color-danger/--layer2-color)
    - style.css: .plan-bar--skipped_rain color→var(--color-text) (白文字解消)
    - style.css: .nav__link/.btn/summary に :focus-visible アウトライン追加
    - style.css: .skip-link/.skip-link:focus スタイル追加
    - base.html: <body>直後にskipリンク追加、<nav>にaria-label、<main>にid="main-content"
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2026-03-09 fix: SoilTemp/SoilWC/SoilEC未接続センサー無視指示をsystem_prompt.txtに追記 (subtask_839)
    CCMノード192.168.1.70のSoilTemp=-10.0等がLLMプロンプトに混入していた問題の
    暫定対処。センサー未接続の旨を明示しLLMが無効値を使わないよう指示。
2026-03-09 fix: system_prompt.txt本番値に逆同期（3項目7箇所）(subtask_842)
    本番RPi(/etc/agriha)の農家調整値をgit版に反映:
    - ルール2高温換気段階: 25/26/26.5℃ → 23/24/25.5℃（より早期開始）
    - ルール4 CO2換気閾値: 600ppm → 300ppm（2箇所）
    - ルール5 CO2換気閾値: 600ppm → 300ppm + duration 300〜600 → 300〜400秒
    理由: CO2発生装置・暖房なし環境では600ppmは不適。
    大気CO2≈420ppmが上限のため300ppmが現実的な換気トリガー。
    git版とRPi本番の差異は上記7箇所のみ（他は完全一致を確認）。
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2026-03-13 feat: unipi-agri-ha/uecs-pico-gateway からコード統合
    uecs-llmをモノリポ化し、分散していた開発資産を集約:
    - src/agriha/vps/: VPS LINE Bot + WGオンボーディング (unipi-agri-ha/linebot)
    - firmware/arduino/: solar_node, env_node_eth (unipi-agri-ha/arduino)
    - firmware/pico/: sensor_node, drainage_node, weather_node (uecs-pico-gateway/firmware)
    - hardware/kicad/: PCB設計 (unipi-agri-ha/hardware)
    - cloud_server/: VPSインストーラ (unipi-agri-ha/cloud_server)
    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
    [actuator_board.kicad_sch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]
2026-03-13 revert: LLMプロバイダーをNullClawに復元
    テスト完了につきOllama→NullClawに戻す。
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2026-03-13 docs: v4 spec・READMEをモノレポ統合+ピタゴラスイッチ実装に合わせて更新
    - §2.2 ディレクトリ構成: unipi-agri-ha → uecs-llm モノレポ反映
    - §1.1 機能カタログ: パス修正・ステータス更新・F21ピタゴラスイッチ追加
    - §3.2 rule_engine: ピタゴラスイッチ段階制御の仕様追記・cron 10分→5分
    - README: Layer 2ピタゴラスイッチ・systemd追加・ディレクトリ表拡充
    - predictive_ventilation_design: ステータスを「実装済み」に更新
    - v2_three_layer_design: DEPRECATED警告追加
    - WG_SETUP_GUIDE: 農家VPN参照先の注意書き追加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
2026-03-13 fix: WG IP枯渇時にLINEエラー返信（無言失敗を防止）
    _next_wg_ipのValueErrorをhandle_followで捕捉し、
    農家に「新規登録を受け付けられません」と返信する。
    farmers_secrets.yamlへの中途半端な書き込みも防止。
2026-03-13 fix: VPS固定IPをハードコードから環境変数/プレースホルダに変更
    - deploy_vps_linebot.sh: VPS_HOST環境変数で上書き可能に
    - .env.example: WG_SERVER_ENDPOINTをプレースホルダに
2026-03-13 refactor: VPSデプロイをconfig化 — ハードコード排除+テンプレート方式
    - CRLF改行修正（onboarding.py他5ファイル）
    - config/vps.conf新規: ドメイン・ポート・パス・WG設定を集約
    - nginx/systemdをテンプレート化（__PLACEHOLDER__方式、sed展開）
    - deploy_vps_linebot.sh: rsync方式→git clone+VPS上実行方式に全面書換
    - wg_farmers_vps_setup.sh: vps.conf読み込み対応
    - onboarding.py/env.example: toiso.fitハードコード除去
    - README.md: VPSデプロイ手順・vps.conf編集項目一覧追加
2026-03-13 feat: add --remove option to deploy_vps_linebot.sh
    Reverses --setup: stops service, removes systemd/nginx/sudoers/cron/symlink/venv.
    Leaves QR dir, .env, WireGuard, and git repo for manual cleanup.
2026-03-13 fix: VPS systemd compatibility — remove export prefix, fix DB path
    - .env.example: remove "export" prefix (systemd EnvironmentFile requires KEY=VALUE)
    - app.py: os.environ[] → os.getenv() for graceful startup without credentials
    - app.py: DB_PATH default /app/data/ → /var/lib/agriha/ (Docker→VPS migration)
    - onboarding.py: LINE_CHANNEL_ACCESS_TOKEN optional with getenv()
2026-03-13 docs: README update — remove v4 reference, fix VPS description
    - NullClaw section: remove "v4では" prefix (now on main)
    - Directory table: agriha.vps description Docker→systemd+venv
    - VPS deploy: add .env KEY=VALUE format note (no "export" prefix)
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2026-03-14 feat: Phase 0-B Qwen3 1.7Bツール定義改善+追試(subtask_900) — 正答率90.9%達成
    Phase 0-A失敗3件(北閉ch混同/おんど/ch99拒否)を修正:
    - set_relay description: 開(open)=奇数ch/閉(close)=偶数chルール追記
    ch1-ch8全割当明示、「ユーザー指定chをそのまま渡す」明記
    maximum:8 制約削除 → ch99エッジケース対応
    - SYSTEM_PROMPT: 奇数=開/偶数=閉ルール+北閉→ch6例示追加
    センサー取得ひらがな例示(おんど/あつい/なんど)
    ツール不要例外(天気予報/明日の天気/降水確率)追記
    - チャンネル割当更新: ch1-ch8フル定義(ch1=南開,ch2=南閉,...,ch7=天開,ch8=天閉)
    - テ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

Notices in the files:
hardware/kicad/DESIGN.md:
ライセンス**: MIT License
